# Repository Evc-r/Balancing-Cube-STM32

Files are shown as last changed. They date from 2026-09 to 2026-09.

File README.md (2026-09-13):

# STM32F411/ICM-20948 v2 Self-Balancing Cube

Firmware and integration work for a three-axis reaction-wheel balancing cube based on the open-source [remrc/Self-Balancing-Cube](https://github.com/remrc/Self-Balancing-Cube) project.

This version replaces the original ESP32 and MPU6050 with:

- **STM32F411CEU6** microcontroller
- **ICM-20948 v2 breakout** intelligent IMU
- Three **Nidec 24H** reaction-wheel motors with integrated drivers and quadrature encoders
- **3S LiPo** power system

> [!WARNING]
> This project contains high-speed reaction wheels and a LiPo battery. Incorrect PWM polarity, wiring, firmware, or mechanical assembly can cause an unexpected full-power motor start. Read the safety section and complete every diagnostic stage before enabling closed-loop balancing.

## Project status

**Current phase: transitioning into firmware development and software integration.** CAD and the first custom PCB design are complete; electrical bring-up and balancing validation remain ahead.

| Area | Current progress |
|---|---|
| Mechanical design / CAD | Complete for the current build |
| Mechanical assembly | Frame and reaction-wheel assembly completed; final wiring/integration remains |
| Custom four-layer PCB | First design complete and sent for fabrication; known issues require rework and validation |
| STM32 connection | Header spacing mismatch identified; plan to connect the board through wires |
| IMU connection | J7 connector unavailable; plan to solder the IMU wiring directly |
| Firmware | Next active development phase: STM32 project setup, peripheral bring-up, and integration |
| Closed-loop balancing | Not yet demonstrated or validated |

### Current hardware issues

- **Power protection:** an unintended VBAT connection was identified that may bypass the protection stage. A trace-isolation/bodge-wire repair is planned. The repair and its effectiveness have not yet been verified.
- **STM32 header spacing:** the PCB's two long header rows do not match the STM32 board. A wired connection is planned, with a pin-by-pin wiring map and continuity checks before power-up.
- **IMU J7 connection:** direct-soldered wiring is planned because the connector is unavailable. Pin order, logic compatibility, and strain relief still need verification.

These are open integration tasks, not completed fixes. The first PCB revision should not be treated as a validated design for replication.

### Next milestones

1. Document the as-built wiring and verify the PCB rework, power rails, and pin allocation.
2. Create the STM32CubeIDE project and establish basic diagnostics.
3. Bring up safe motor PWM/brake control and validate the encoders.
4. Integrate and characterize the ICM-20948 v2.
5. Implement attitude estimation, calibration, and fault handling.
6. Perform output-limited control tests, then tune vertex balancing.
7. Add edge balancing and usability features after the initial controller is reliable.

See [JOURNAL.md](JOURNAL.md) for retrospective CAD/PCB notes and future session logs, and [PROJECT_PLAN.md](PROJECT_PLAN.md) for the planned architecture and acceptance criteria.

### Documentation and project files

The repository currently contains project documentation, not a buildable firmware release. CAD, KiCad source files, manufacturing outputs, photos, and firmware still need to be added here. The existing [project media folder](https://drive.google.com/drive/folders/1Wyz73s2HkP9Nr1Q7drfzrUGMNGJb-3j-?usp=drive_link) is linked for reference.

Earlier CAD/PCB work is documented retrospectively without reconstructed work hours. Future sessions should record what changed, evidence, test results, and actual tracked time.

## Why this is a firmware port, not a board substitution

The original Arduino/ESP32 sketch cannot be compiled unchanged for this hardware. Several subsystems are fundamentally different:

| Original design | This design |
|---|---|
| ESP32 Arduino | STM32CubeIDE and STM32 HAL |
| MPU6050 raw accelerometer/gyro | ICM-20948 v2 raw accelerometer/gyro with STM32 attitude estimation |
| Original complementary filter | STM32 complementary/Mahony filter using calibrated ICM-20948 data |
| GPIO encoder interrupts | STM32 hardware timer encoder mode |
| ESP32 LEDC PWM | STM32 timer PWM |
| EEPROM API | Versioned internal Flash record with CRC |
| BluetoothSerial | USB CDC or UART initially |
| 15 ms `millis()` loop | Deterministic 200 Hz hardware-timed loop |

The original three-wheel coordinate transformations and controller concept remain useful, but controller gains, timing, calibration, drivers, and safety behavior must be implemented and tested again.

## Hardware

### Required core components

- STM32F411CEU6 board, typically a Black Pill-style board
- ICM-20948 v2 breakout
- Three Nidec 24H motors with integrated motor electronics and encoder outputs
- 3S LiPo battery and suitable connector
- Regulated logic supply appropriate for the selected STM32 board and peripherals
- Motor brake, direction, PWM, and encoder wiring
- Battery-voltage divider
- Active buzzer or another fault indicator
- USB-to-UART adapter if USB CDC is not used
- Physical power disconnect

### Items that must be verified before connection

ICM-20948 v2 breakout and STM32 breakout boards vary. Confirm from the actual boards and schematics:

- STM32 board HSE frequency; this project currently assumes 25 MHz
- ICM-20948 v2 regulator and permitted supply voltage
- ICM-20948 v2 logic voltage, pull-ups, level shifters, and interface-selection pins
- Motor encoder output voltage and whether it is push-pull or open-collector
- Need for external encoder pull-ups
- Maximum battery-divider voltage at a fully charged 3S pack
- Ground continuity between logic, IMU, motors, and battery measurement

Do not assume that a module accepting 5 V power also has 5 V-safe signal pins.

## Planned firmware architecture

The architecture, interfaces, safety behavior, and timing values below are implementation targets. Firmware bring-up, execution timing, and successful balancing have not been verified.

```text
ICM-20948 v2 interrupt
    -> SPI or I2C transfer
    -> register/FIFO driver and sample validation
    -> calibrated accelerometer and gyro sample
    -> STM32 attitude estimator
    -> latest timestamped quaternion and angular rate

200 Hz control timer
    -> validate IMU freshness
    -> read three encoder counters
    -> calculate quaternion balance error
    -> determine vertex, edge, fallen, or fault state
    -> run state-feedback controller
    -> mix X/Y/Z corrections into three wheel commands
    -> update PWM, direction, and brake

Background processing
    -> command interface and telemetry
    -> calibration workflow
    -> Flash parameter storage
    -> battery monitoring
    -> diagnostics and fault reporting
```

Serial output, Flash writes, and blocking IMU transfers must never run inside the control interrupt.

## Clock and timing

A 25 MHz external crystal is assumed for the selected board and still needs confirmation; it is not the intended CPU speed. The STM32F411 will be configured through its PLL for a target system clock of **100 MHz**.

Initial timing targets:

| Function | Target |
|---|---:|
| ICM-20948 accelerometer and gyro sampling | 500 Hz initially |
| STM32 attitude estimator | 500 Hz initially |
| Balance controller | 200 Hz initially |
| Motor PWM | 20 kHz |
| Maximum accepted IMU age | 15 ms initially |

The final CubeMX clock tree must also produce a valid peripheral clock if USB CDC is enabled.

## ICM-20948 v2 approach

The ICM-20948 is a 9-axis IMU containing a 3-axis gyroscope, 3-axis accelerometer, AK09916 3-axis magnetometer, FIFO, programmable filters, and an embedded DMP. It supports SPI up to 7 MHz or I2C up to 400 kHz. The initial controller will read raw accelerometer and gyroscope data and perform attitude estimation on the STM32.

Initial sensing strategy:

- Gyroscope and accelerometer sampled at 500 Hz
- Configurable digital low-pass filtering
- Startup stationary gyro-bias calibration
- Six-axis complementary or Mahony quaternion estimator on the STM32
- Magnetometer disabled for balancing initially because motor currents can disturb it
- DMP integration deferred until the raw-data controller is validated

SPI is preferred for deterministic high-rate acquisition. I2C is acceptable for initial testing if the breakout exposes it more conveniently. Connect and use the data-ready interrupt. Every accepted sample must be timestamped locally, checked for plausibility, and monitored for staleness.

The exact v2 breakout must be inspected for its regulator, level shifting, pull-ups, address selection, and exposed interrupt/chip-select pins. The bare ICM-20948 has lower VDDIO limits than the STM32's 3.3 V logic, so compatibility depends on the breakout circuitry.

## Coordinate frames

All sensor measurements must be transformed into a documented mechanical cube frame before they reach the controller.

The mapping will be bench-tested so that positive physical rotation around cube X, Y, and Z produces positive cube-frame gyro X, Y, and Z respectively. Axis swaps and sign changes will be centralized in one module rather than distributed through the controller.

The wheel numbering, positive rotation direction, encoder sign, and cube-frame force direction will also be documented before closed-loop testing.

## Calibration

The MPU6050 offset procedure will be replaced with two layers: stationary accelerometer/gyro calibration, followed by quaternion reference calibration for the mechanical vertex and edge poses.

The firmware will store:

- Vertex reference quaternion
- Edge reference quaternion
- Sensor-to-cube mapping
- Controller gains
- Battery calibration
- Version, record length, magic value, and CRC32

At runtime the orientation error is calculated from:

```text
q_error = inverse(q_reference) * q_current
```

Calibration will only be accepted when IMU data is fresh, sensor accuracy is acceptable, gyro magnitude is low, and the pose remains stable for a defined interval.

Planned commands:

```text
cal vertex
cal edge
cal status
save
```

An absent, corrupt, or incompatible calibration record must prevent balancing.

## Controller

The controller will retain the reference project's general state-feedback structure while using explicit units:

```text
wheel command =
      angle gain * angle error
    + gyro gain * angular velocity
    + wheel velocity gain * wheel velocity
    + wheel position gain * accumulated wheel position
```

Yaw damping uses vertical-axis gyro and combined wheel motion.

The reference three-wheel transformation will be ported and verified against the actual wheel layout:

```text
m1 = (0.5*x - 0.866*y) / 1.37 + z
m2 = (0.5*x + 0.866*y) / 1.37 + z
m3 = -x / 1.37 + z
```

Original numeric gains will not be copied blindly. The new firmware uses different units, sample timing, sensor latency, encoder scaling, and motor-command scaling.

## Development environment

Planned tools:

- STM32CubeIDE
- STM32CubeMX configuration integrated with CubeIDE
- ST-LINK programmer/debugger
- Git
- Serial terminal
- Multimeter
- Oscilloscope or logic analyzer strongly recommended

The repository will eventually contain the complete CubeIDE project and generated configuration needed for a clean build.

## Planned source layout

```text
Core/Inc/                Public module headers
Core/Src/                Application and driver implementation
Drivers/                 STM32 HAL and device support
Docs/                    Wiring, coordinate frames, calibration, and tuning
Tests/                   Host-side and hardware test support
JOURNAL.md               Retrospective hardware notes and future session logs
PROJECT_PLAN.md          Detailed engineering plan
README.md                 Project overview and bring-up guide
```

## Bring-up order

Do not skip ahead to balance tuning. Each stage is a gate for the next.

### 1. Power and MCU

- Verify every regulated rail without motor output enabled.
- Confirm the STM32 HSE and generated 100 MHz clock.
- Establish UART or USB diagnostics.
- Report firmware version and reset cause at boot.

### 2. Brake and PWM

- Assert brake before PWM initialization.
- Test one motor at a time at a low command limit.
- Verify direction control.
- Measure the real zero-torque PWM polarity.
- Confirm reset and debugger attachment never start a motor.

The reference Nidec interface uses active-low PWM. Treat that as a hypothesis to verify electrically, not an assumption.

### 3. Encoders

- Configure timer encoder mode where possible.
- Verify both channels of each encoder.
- Test direction, stationary noise, wraparound, and maximum speed.
- Document positive directions and counts per revolution.

### 4. ICM-20948 v2

- Verify WHO_AM_I and configure the register banks, ranges, filters, FIFO, and data-ready interrupt.
- Read calibrated accelerometer and gyro samples continuously.
- Run the STM32 attitude estimator and measure sample interval, age, bias, saturation, and communication errors.
- Verify all cube-frame axes.
- Confirm individual motor operation does not interrupt reports.

### 5. Calibration and storage

- Capture stable vertex and edge references.
- Save a versioned record with CRC.
- Verify save, reboot, load, and corrupt-record behavior.

### 6. Output-limited closed-loop testing

- Use a support or tether.
- Apply a low motor-command limit.
- Verify by hand that every correction opposes the fall.
- Test stale-IMU and excessive-tilt shutdown.

### 7. Vertex tuning

- Tune angle feedback.
- Add gyro damping.
- Add wheel-velocity feedback.
- Add a small wheel-position term to prevent saturation.
- Add yaw damping.

### 8. Edge balancing and refinements

Only after vertex balance is reliable:

- Implement edge state detection and reference
- Tune an independent edge controller
- Add wireless tuning
- Add status LEDs and improved telemetry

## Serial interface

Initial transport will be UART or USB CDC. Planned commands include:

```text
help
status
faults
imu
encoders
battery
motor <1|2|3> <command>
motor stop
brake <on|off>
cal vertex
cal edge
cal status
save
set <parameter> <value>
get <parameter>
telemetry <on|off>
```

Manual motor commands will only work in a diagnostic state with the balance controller disabled.

## Safety behavior

The firmware must disable motor output if any of these conditions occurs:

- Boot or calibration is in progress
- IMU data is missing, invalid, saturated, or stale
- ICM-20948 v2 identity/configuration check fails or a reset is detected
- Tilt exceeds the allowed range
- Battery voltage is below the safe threshold
- Encoder plausibility fails
- Control-loop overrun occurs
- A NaN or infinity reaches the controller
- A stop command is received

Physical precautions:

- Wear eye protection during powered tests.
- Use a tether or fixture for initial control tests.
- Keep hands, hair, tools, and loose wiring away from the wheels.
- Secure the LiPo and all connectors mechanically.
- Keep an accessible power disconnect.
- Do not charge the LiPo inside the cube.
- Use independent undervoltage and charging protection appropriate for the pack.
- Never write Flash while the cube is balancing.

## Testing and telemetry

Host-side tests are planned for:

- Quaternion normalization, inversion, and sign handling
- Reference-orientation error
- Coordinate transformations
- Three-wheel mixing and inverse mixing
- Saturation and accumulated-state limits
- Flash record CRC and version checks
- Fault-state transitions

Runtime telemetry will include:

- Control-loop execution time
- IMU sample age and accuracy
- Quaternion and angle errors
- Gyro values
- Encoder deltas and wheel velocities
- Individual controller terms
- Motor commands before and after saturation
- Battery voltage
- Active state and fault flags

## Definition of the first release

Version `v0.1.0` will require:

- A clean build from documented STM32CubeIDE prerequisites
- Documented pin map and wiring
- Passing motor and encoder diagnostics
- Timestamped and fault-monitored ICM-20948 v2 samples and STM32 attitude estimates
- CRC-protected vertex calibration
- Repeatable vertex balance without wheel-speed saturation
- Reliable stale-IMU, over-tilt, low-battery, and software-fault shutdown
- Documented controller units, gains, calibration, and bring-up procedure

Edge balancing may ship in a later release if it is not reliable enough for `v0.1.0`.

## Contributing and development notes

Until the first hardware bring-up is complete, interface definitions, pin assignments, and controller parameters should be considered provisional.

When making changes:

- Keep hardware access separate from control mathematics.
- State physical units in names or comments.
- Do not mix sensor-frame and cube-frame values.
- Include safe defaults and failure behavior.
- Update documentation whenever pin assignments, coordinate signs, or calibration data change.
- Record test conditions and telemetry when changing controller gains.

## Acknowledgements

This project is derived from and inspired by Remigijus's [Self-Balancing-Cube](https://github.com/remrc/Self-Balancing-Cube). The original repository established the mechanical concept, Nidec motor interface, wheel mixing, balance-control structure, and practical build approach.

This repository is an independent STM32F411/ICM-20948 v2 port and will require new firmware, calibration, validation, and gain tuning.

## License

No license has been selected yet. Until a license file is added, normal copyright restrictions apply to original work in this repository. Any reused or adapted material must continue to comply with its original licensing terms.

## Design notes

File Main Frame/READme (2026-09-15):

Please note that the current CAD files (V1) committed to this Github are NOT FINAL, and have been changed, edited, and finished since publication.

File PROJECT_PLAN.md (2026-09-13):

# STM32F411/ICM-20948 v2 Self-Balancing Cube Project Plan

## Current progress

CAD and mechanical assembly are completed. The first custom four-layer PCB design is completed and was sent for fabrication. The project is moving into firmware development/software integration. PCB rework and electrical validation are still pending; firmware bring-up and successful balancing have not been verified.

The custom PCB is part of the current build. A VBAT connection may bypass the protection circuit; a bodge repair is planned, but its completion and effectiveness are unverified. The STM32 header spacing is incorrect, so a wired STM32 connection is planned. The J7 IMU connector is unavailable, so directly soldering its wiring is planned. These repairs and connections have not been verified.

The architecture, rates, and interfaces below are **implementation targets**, not measured performance or completed firmware. M0 remains an open validation gate; M1–M9 are upcoming milestones. See [README.md](README.md) for the status summary and [JOURNAL.md](JOURNAL.md) for progress notes.

## 1. Goal

Port and improve the control system from [remrc/Self-Balancing-Cube](https://github.com/remrc/Self-Balancing-Cube) for this hardware:

- STM32F411CEU6 microcontroller, with an assumed 25 MHz HSE to confirm and a target 100 MHz system clock
- ICM-20948 v2 breakout IMU
- Three Nidec 24H reaction-wheel motors with direction, active-low PWM, shared brake, and quadrature encoders
- 3S LiPo power system

The first release target is safe, repeatable vertex balancing. Edge balancing and wireless tuning come afterward.

## 2. Scope

### Included

- Integration and validation of the existing custom four-layer PCB
- Native STM32CubeIDE/HAL firmware
- Three 20 kHz motor PWM outputs
- Three direction outputs and one shared brake output
- Three hardware quadrature encoder interfaces where pin mapping permits
- ICM-20948 v2 quaternion and calibrated gyro acquisition
- Sensor-to-cube coordinate transformation
- Quaternion-based vertex and edge calibration
- State-feedback balance controller
- Battery monitoring and fault shutdown
- USB CDC or UART diagnostics
- Flash-backed calibration and parameter storage

### Deferred until balancing works

- Bluetooth/BLE tuning
- WS2812 status LEDs
- Automated gain tuning
- Jump-up maneuver

## 3. Main changes from the reference firmware

| Reference project | This project |
|---|---|
| ESP32 Arduino | STM32CubeIDE with STM32 HAL |
| ESP32 LEDC PWM | STM32 timer PWM |
| GPIO encoder interrupts | Hardware timer encoder mode |
| MPU6050 raw readings | ICM-20948 v2 register/FIFO accelerometer and gyro samples |
| Original complementary filter | STM32 complementary/Mahony quaternion estimator |
| Accelerometer offset calibration | Quaternion reference calibration |
| EEPROM API | Internal Flash record with version and CRC |
| BluetoothSerial | USB CDC or UART first; external wireless later |
| 15 ms millis loop | Deterministic 200 Hz hardware-timed loop |

The original three-wheel mixing and controller structure will be retained only after signs, units, and scaling are verified.

## 4. Architecture

```text
ICM-20948 data-ready INT
    -> SPI/I2C register or FIFO transfer
    -> calibrated accelerometer + gyro sample
    -> STM32 attitude estimator
    -> latest timestamped quaternion + angular rate

200 Hz control timer
    -> copy latest valid IMU sample
    -> read encoder counters
    -> calculate quaternion error from balance reference
    -> run vertex/edge state machine
    -> run state-feedback controller
    -> convert X/Y/Z command to three wheel commands
    -> update PWM, direction, and brake

Background tasks
    -> serial commands and telemetry
    -> calibration workflow
    -> Flash save/load
    -> battery measurement
    -> fault reporting
```

The control interrupt must never print serial data, write Flash, or perform a blocking ICM-20948 v2 transaction.

## 5. Proposed repository structure

```text
Core/Inc/
  app_config.h
  app_types.h
  balance_controller.h
  icm20948_driver.h
  calibration.h
  command_interface.h
  coordinate_transform.h
  encoder.h
  fault_manager.h
  motor_control.h
  parameter_store.h
  telemetry.h
Core/Src/
  balance_controller.c
  icm20948_driver.c
  calibration.c
  command_interface.c
  coordinate_transform.c
  encoder.c
  fault_manager.c
  motor_control.c
  parameter_store.c
  telemetry.c
  main.c
Docs/
Tests/
PROJECT_PLAN.md
README.md
JOURNAL.md
```

Keep hardware access outside the controller mathematics so transforms, mixing, safety logic, and quaternion calculations can be unit tested.

## 6. Units and core data

Use explicit units everywhere:

- Angle: radians
- Angular velocity: radians/second
- Wheel velocity: counts/second initially, later radians/second
- Control period: seconds
- Motor command: normalized -1.0 to +1.0
- Battery voltage: volts

```c
typedef struct { float w, x, y, z; } Quaternion;
typedef struct { float x, y, z; } Vector3f;

typedef struct {
    Quaternion orientation;
    Vector3f accel_m_s2;
    Vector3f gyro_rad_s;
    uint32_t timestamp_us;
    uint8_t validity and saturation status;
    bool valid;
} ImuSample;

typedef struct {
    uint32_t version;
    Quaternion vertex_reference;
    Quaternion edge_reference;
    float sensor_to_cube_rotation[3][3];
    uint32_t crc32;
} CalibrationRecord;
```

## 7. Hardware and CubeMX plan

### Clock

- Confirm the board actually uses a 25 MHz HSE.
- Configure the PLL for a 100 MHz system clock.
- Verify APB timer clocks in CubeMX.
- If USB CDC is used, ensure a valid 48 MHz USB clock.
- Measure a timed GPIO output to confirm the generated clock configuration.

### Timer allocation

Conceptual allocation only; final assignments depend on exposed pins and alternate-function conflicts:

```text
TIM1 CH1-CH3: motor PWM 1-3
TIM2 CH1/CH2: encoder 1
TIM3 CH1/CH2: encoder 2
TIM4 CH1/CH2: encoder 3
TIM5: control scheduler or microsecond time base
```

Complete the CubeMX pin allocation before permanent harness or PCB wiring. If all three encoder timers cannot be mapped, use hardware encoder mode for the fastest wheels and a validated interrupt decoder for the remaining wheel.

### Motor interface

- PWM frequency: 20 kHz.
- Preserve active-low PWM until verified with a meter or oscilloscope.
- Initialize every PWM compare register to zero-torque before releasing brake.
- Keep the shared brake asserted during boot, faults, Flash writes, and debugger halts.
- Test one motor at a time with a low command limit.

### Encoders

- Confirm output voltage and whether outputs are push-pull or open-collector.
- Add external pull-ups if required.
- Do not exceed the selected STM32 pin voltage limits.
- Configure timer input filtering if noise creates false counts.
- Verify the direction sign of every wheel independently.

### ICM-20948 v2

Prefer SPI if the exact ICM-20948 v2 breakout board exposes it correctly. Otherwise use 400 kHz I2C with INT and RESET connected.

Inspect the exact breakout for:

- Regulator configuration
- Logic voltage
- I2C pull-ups
- Level shifters
- Interface-selection pins

Do not assume every board sold as ICM-20948 v2 breakout has the same circuit.

### Battery ADC

- Use a divider safe at maximum charged 3S voltage.
- Ensure the ADC input cannot exceed its limit.
- Add RC filtering near the MCU.
- Calibrate against a multimeter.
- Retain independent LiPo undervoltage protection.

## 8. IMU strategy

The ICM-20948 contains a 3-axis gyroscope, 3-axis accelerometer, AK09916 3-axis magnetometer, FIFO, programmable digital filters, and an embedded DMP. It supports SPI up to 7 MHz or I2C up to 400 kHz.

Initial implementation:

- Read raw accelerometer and gyroscope data through SPI where possible
- Configure suitable full-scale ranges and digital low-pass filters
- Use the data-ready interrupt and optionally the FIFO
- Sample accelerometer and gyro at 500 Hz initially
- Calibrate stationary gyro bias at startup
- Apply stored accelerometer scale/offset correction if characterization shows it is required
- Run a six-axis complementary or Mahony quaternion estimator on the STM32 at 500 Hz
- Run the balance controller at 200 Hz using the freshest complete estimate
- Leave the magnetometer disabled for balancing initially because motor currents can disturb it
- Defer DMP integration until the raw-data controller is validated

SPI is preferred for predictable high-rate acquisition. I2C at 400 kHz is acceptable for early tests. Every sample must be timestamped locally and checked for stale data, clipping, impossible jumps, communication errors, and estimator validity.

The exact v2 breakout must be inspected for regulator, voltage translation, pull-ups, address selection, and exposed INT/CS pins. The bare ICM-20948 has stricter VDDIO limits than 3.3 V, so breakout-level compatibility must be verified rather than assumed.

Initial timing targets:

```text
Accelerometer/gyro sampling: 2 ms (500 Hz)
STM32 attitude estimation:   2 ms (500 Hz)
Control-loop interval:       5 ms (200 Hz)
Maximum accepted sample age: 15 ms initially
```

The controller must enter a safe fault state if samples stop, WHO_AM_I/configuration checks fail, the sensor resets, readings saturate unexpectedly, or the attitude estimator becomes invalid.

## 9. Coordinate frames and calibration

### Sensor-to-cube transform

Implement one central sensor-to-cube transformation. Do not scatter sign swaps through controller code.

Verify on the bench:

- Positive cube rotation around X produces positive cube-frame gyro X.
- Positive cube rotation around Y produces positive cube-frame gyro Y.
- Positive cube rotation around Z produces positive cube-frame gyro Z.

Document the mapping in a future `Docs/COORDINATE_FRAMES.md`.

### Quaternion references

Store separate vertex and edge reference quaternions. At runtime:

```text
q_error = inverse(q_reference) * q_current
```

For small errors:

```text
angle_x ~= 2 * q_error.x
angle_y ~= 2 * q_error.y
angle_z ~= 2 * q_error.z
```

Normalize quaternions and enforce a consistent quaternion hemisphere so equivalent q and -q representations do not cause discontinuities.

Calibration commands:

```text
cal vertex
cal edge
cal status
save
```

Calibration capture requires fresh data, acceptable sensor accuracy, low gyro magnitude, and a stable orientation for a defined duration.

## 10. Controller plan

### Vertex controller

```text
u_x = K_angle_x * angle_error_x
    + K_gyro_x * gyro_x
    + K_wheel_v_x * wheel_velocity_x
    + K_wheel_p_x * wheel_position_x

u_y = K_angle_y * angle_error_y
    + K_gyro_y * gyro_y
    + K_wheel_v_y * wheel_velocity_y
    + K_wheel_p_y * wheel_position_y

u_z = K_yaw_rate * gyro_z
    + K_yaw_wheel * wheel_velocity_z
```

Use saturation and limit accumulated wheel-position terms.

### Three-wheel mixing

Port and verify the reference equations:

```text
m1 = (0.5*x - 0.866*y) / 1.37 + z
m2 = (0.5*x + 0.866*y) / 1.37 + z
m3 = -x / 1.37 + z
```

Verify the inverse transformation against actual wheel locations and encoder signs.

### Tuning order

1. Verify signs through hand-held, output-limited tests.
2. Add low-gain angle feedback.
3. Add gyro damping.
4. Tune angle and gyro terms for bounded behavior.
5. Add wheel-velocity feedback.
6. Add a small wheel-position term to prevent saturation.
7. Add yaw damping.
8. Implement and tune edge balancing separately.

Do not copy the original numeric gains: the units, loop period, IMU latency, encoder scaling, and motor-command scaling have changed.

## 11. Safety requirements

Disable motor output when:

- Firmware is booting or calibrating.
- IMU data is missing, stale, or invalid.
- A ICM-20948 v2 reset is detected.
- Tilt exceeds the configured fall threshold.
- Battery voltage is below the safe threshold.
- Encoder plausibility fails.
- The control loop overruns.
- A NaN or infinity enters the controller.
- An explicit stop command is received.

Additional requirements:

- Begin with a low motor-command limit.
- Use a physical support, tether, eye protection, and an accessible power disconnect.
- Secure the battery and wiring.
- Never write Flash while balancing.
- Ensure debugger halt cannot leave motor PWM active.
- Use independent 3S LiPo protection.

## 12. Serial interface

Initial transport: UART or USB CDC.

Planned commands:

```text
help
status
faults
imu
encoders
battery
motor <1|2|3> <command>
motor stop
brake <on|off>
cal vertex
cal edge
cal status
save
set <parameter> <value>
get <parameter>
telemetry <on|off>
```

Manual motor commands are allowed only in a diagnostic state with the balance controller disabled.

## 13. Flash storage

Store a versioned record containing:

- Magic value
- Structure version and length
- Vertex and edge reference quaternions
- Axis mapping
- Controller gains
- Battery calibration
- CRC32

Invalid magic, version, length, or CRC must load safe defaults and require calibration. Save only with motor output disabled and brake asserted.

## 14. Milestones

### M0 - Hardware confirmation

- Document and verify the planned VBAT/protection repair before powering the integrated system; confirm the intended power path and protection behavior.
- Map and continuity-check the planned wired STM32 connection and direct-soldered IMU connection.
- Record exact STM32 board and ICM-20948 v2 breakout module.
- Confirm motor connector, encoder type, and logic voltage.
- Confirm battery, regulator, divider, and brake wiring.
- Complete a conflict-free CubeMX draft pin map.

Exit: planned repairs and connections are completed and verified, the intended power path and protection behavior are confirmed, and no voltage-level or pin-allocation questions remain.

### M1 - STM32 bring-up

- Generate CubeMX project.
- Verify intended system clock.
- Enable UART or USB logging.
- Add microsecond timing and fault indication.

Exit: measured clock and stable diagnostics.

### M2 - Motor and brake diagnostics

- Configure PWM, direction, and shared brake.
- Reproduce the reference motor test at low command.
- Confirm true zero-torque PWM polarity.

Exit: each motor runs independently in both directions, and resets never cause motion.

### M3 - Encoder bring-up

- Configure three encoder interfaces.
- Measure signed deltas at a fixed interval.
- Test direction, stationary noise, wraparound, and maximum speed.

Exit: all encoders count reliably with documented signs.

### M4 - ICM-20948 v2 bring-up

Tasks:

- Verify WHO_AM_I and banked-register access.
- Configure accelerometer and gyro ranges, sample rates, filters, interrupt, and FIFO if used.
- Calibrate stationary gyro bias.
- Timestamp samples and monitor data age, saturation, and communication faults.
- Implement sensor-to-cube mapping.
- Implement and validate the STM32 attitude estimator.

Exit criteria:

- Raw accelerometer and gyro samples remain continuous while motors run individually.
- Sample interval, bias, clipping, and estimator health are monitored.
- All three cube-frame gyro signs are verified.
- Static orientation estimates are stable and return correctly after slow tilts.
- A disconnected, reset, or misconfigured IMU generates a safe fault.

### M5 - Calibration and persistence

- Capture stable vertex and edge references.
- Implement quaternion error.
- Add versioned Flash storage with CRC.

Exit: calibration survives reboot; absent or corrupt calibration cannot enable balancing.

### M6 - Low-power closed-loop tests

- Port wheel mixing.
- Add output-limited angle and gyro control.
- Verify every correction sign while holding the cube.
- Add stale-data and over-angle shutdown.

Exit: corrections oppose disturbances on both axes, with reliable fault shutdown.

### M7 - Vertex balancing

- Tune angle and gyro terms.
- Add wheel-velocity and wheel-position feedback.
- Add yaw damping and telemetry.

Exit: repeatable balance without wheel saturation and with predictable fall shutdown.

### M8 - Edge balancing

- Determine correct edge axis and wheel combination.
- Implement edge detection and independent gains.

Exit: repeatable edge balance without degrading vertex behavior.

### M9 - Release preparation

- Add optional wireless tuning and status indicators.
- Complete build, wiring, calibration, and tuning documentation.
- Tag the first stable release.

Exit: another person can build, flash, calibrate, and test the cube from the repository instructions.

## 15. Testing and telemetry

Host-side tests should cover:

- Quaternion normalization, inverse, and hemisphere handling
- Reference error calculation
- Coordinate transforms
- Wheel mixing and inverse mixing
- Saturation and accumulated-state limiting
- Flash CRC and version validation
- Fault-state transitions

Telemetry should include:

- Timestamp and loop execution time
- IMU age and accuracy
- Quaternion and angle errors
- Gyro X/Y/Z
- Encoder deltas and wheel velocities
- Individual controller terms
- Saturated and unsaturated motor commands
- Battery voltage
- Active state and fault flags

## 16. Principal risks

| Risk | Mitigation |
|---|---|
| CEU6 timer pin conflicts | Finish CubeMX allocation before wiring |
| Active-low PWM causes startup torque | Measure idle polarity and initialize PWM before brake release |
| Encoder voltage exceeds GPIO limit | Verify electrically and level-shift if required |
| ICM-20948 v2 breakout variants differ | Inspect and document the exact module |
| Fusion latency destabilizes control | Timestamp samples and tune controlled bandwidth |
| Motor magnetic interference | Keep the magnetometer out of the initial balance estimator |
| Quaternion sign discontinuity | Enforce a consistent hemisphere |
| Coordinate signs are incorrect | Centralize and bench-verify transforms |
| Original gains have incompatible units | Retune from low output limits using explicit units |
| Flash stalls execution | Save only while motors are disabled |
| LiPo over-discharge | Conservative thresholds plus independent protection |
| Debug halt leaves motors active | Safe debug configuration and physical disconnect |

## 17. Definition of v0.1.0

The first successful release requires:

- Clean STM32CubeIDE build from documented prerequisites
- Documented wiring and pin map
- Passing motor and encoder diagnostics
- Timestamped and fault-monitored ICM-20948 v2 reports
- CRC-protected vertex calibration
- Repeatable vertex balance without wheel saturation
- Reliable stale-IMU, over-tilt, low-battery, and software-fault shutdown
- Documented controller units and gains
- Complete bring-up and calibration instructions

Edge balancing may be released later if it is not reliable enough for v0.1.0.

## 18. Immediate next actions

Before powered bring-up: document the PCB rework, verify the intended power path and protection behavior after the planned repair, and check the STM32/IMU wiring against the schematic. Add CAD, KiCad sources, and photos to the repository as they become available. Start session-based journaling and time tracking with firmware work.

1. Document both sides and pin labels of the exact STM32F411 and ICM-20948 v2 breakout boards.
2. Confirm the 25 MHz HSE and decide whether USB CDC is required.
3. Build the complete pin inventory and CubeMX timer allocation.
4. Measure motor encoder logic voltage and determine pull-up requirements.
5. Create the STM32CubeIDE project and UART diagnostics.
6. Implement brake-safe boot behavior before applying motor power.
7. Bring up one PWM channel and motor at low command.
8. Bring up its encoder in timer encoder mode.
9. Repeat for all motors and encoders.
10. Implement ICM-20948 v2 communication and log quaternion, gyro, interval, age, and accuracy before writing balance-control code.

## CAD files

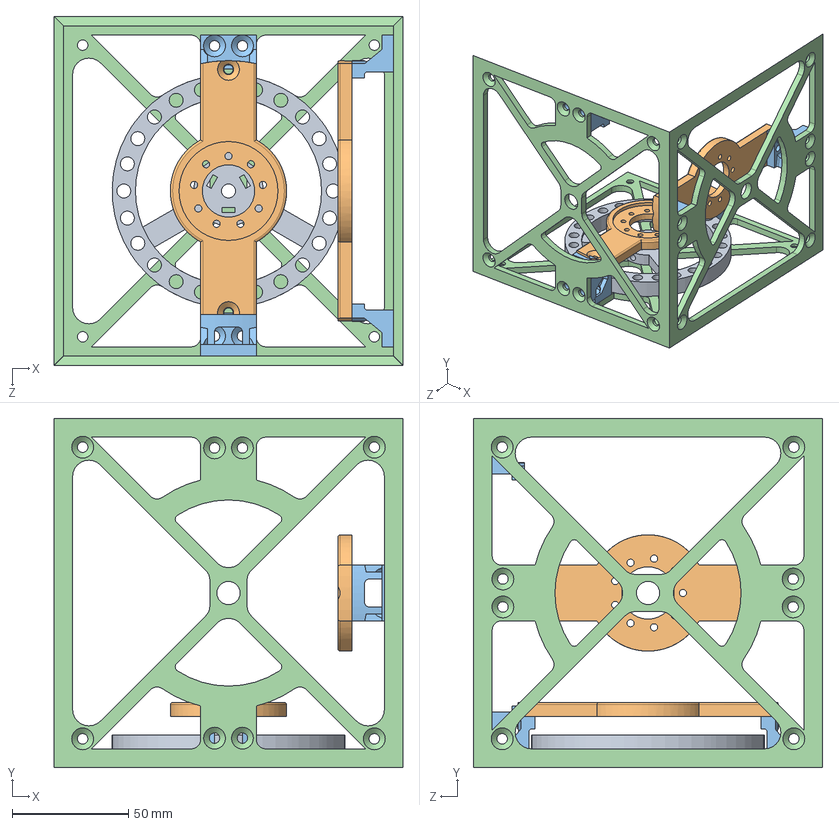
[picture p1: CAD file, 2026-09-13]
Main Frame/Assem1.SLDASM
150.0 x 150.0 x 150.0 mm
rwframev2.2 x 3
motorholderconnectorv0.1 x 3
motorholderv0.1 x 2
reactionwheelv0.1

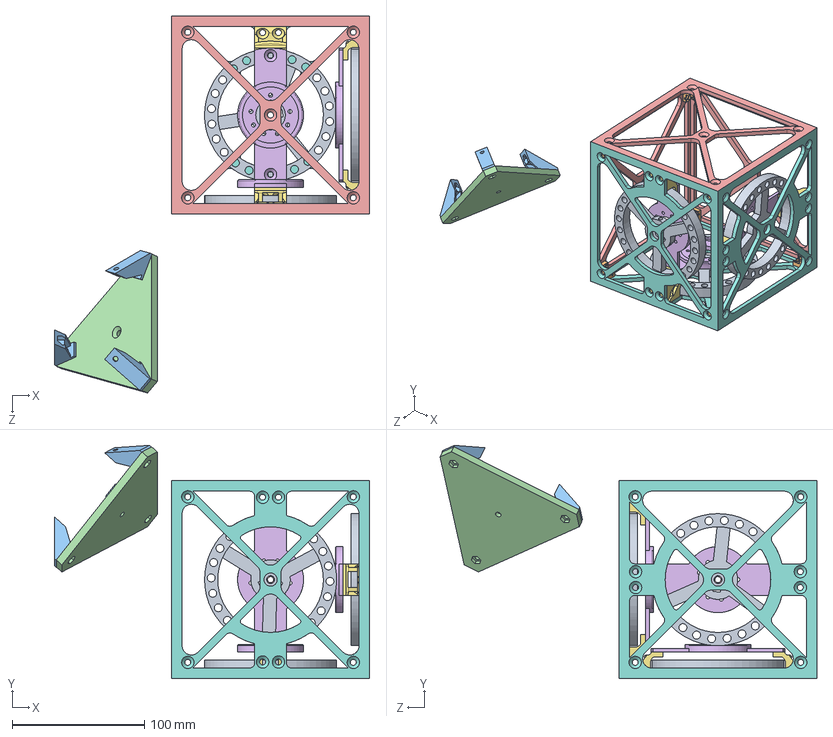
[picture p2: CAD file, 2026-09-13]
Main Frame/Assem2.SLDASM
238.7 x 176.7 x 285.5 mm
rwframev2.2 x 3
motorholderconnectorv0.2 x 3
motorholderv0.2 x 3
nframev0.1 x 3
elecframev0.1
elecframeconnectorv0.1 x 3
cornerconnectorv0.1 x 8
reactionwheelv0.1 x 3

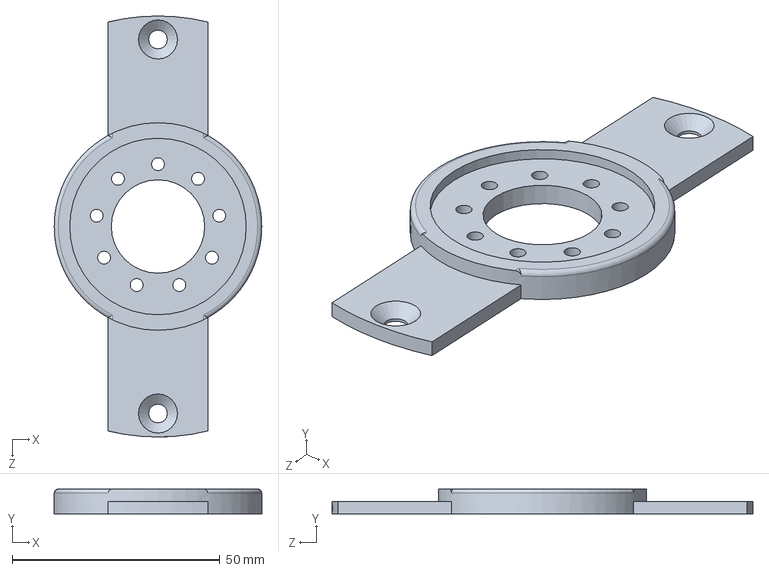
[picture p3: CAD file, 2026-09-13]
Main Frame/motorholderv0.2.SLDPRT
50.0 x 6.00 x 101.4 mm

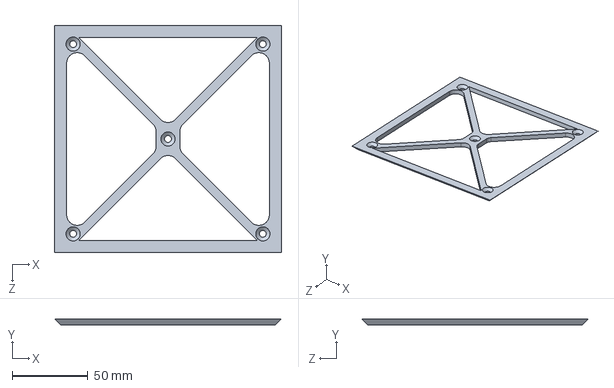
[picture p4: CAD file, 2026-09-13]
Main Frame/nframev0.1.SLDPRT
150.0 x 4.00 x 150.0 mm

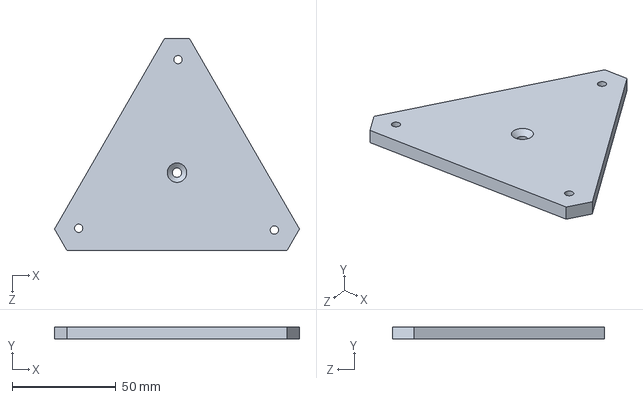
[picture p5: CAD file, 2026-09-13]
Main Frame/elecframev0.1.SLDPRT
118.0 x 6.00 x 102.2 mm

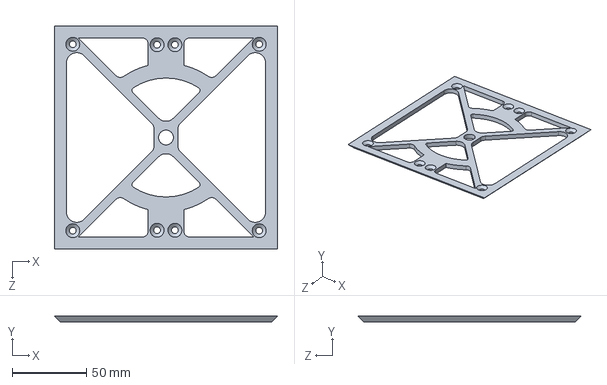
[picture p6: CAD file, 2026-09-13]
Main Frame/rwframev2.2.SLDPRT
150.0 x 4.00 x 150.0 mm

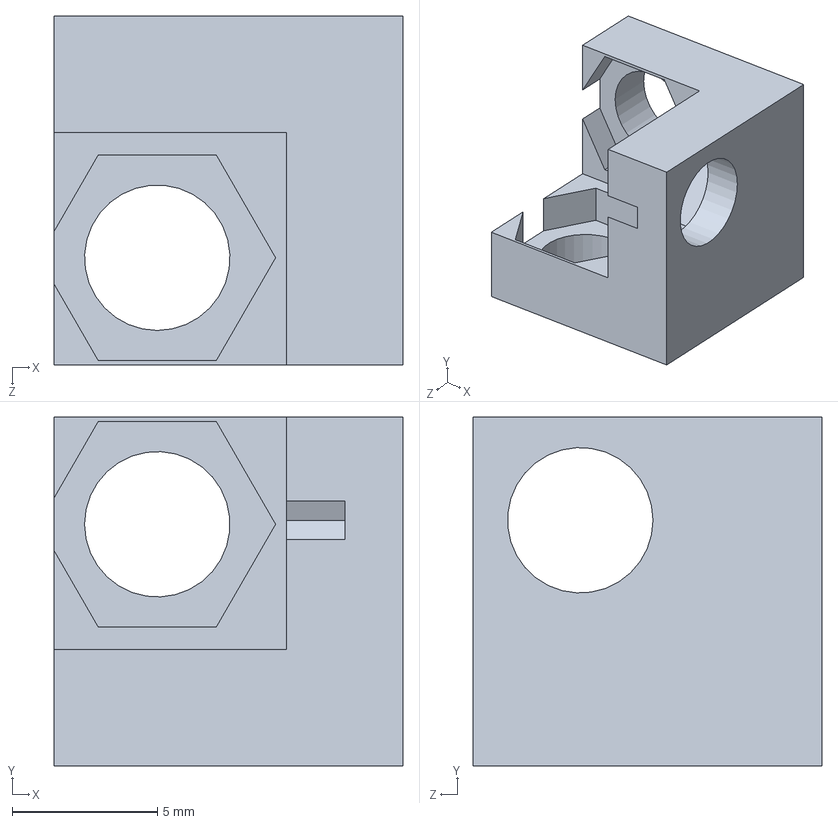
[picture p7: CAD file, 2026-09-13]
Main Frame/cornerconnectorv0.1.SLDPRT
12.0 x 12.0 x 12.0 mm

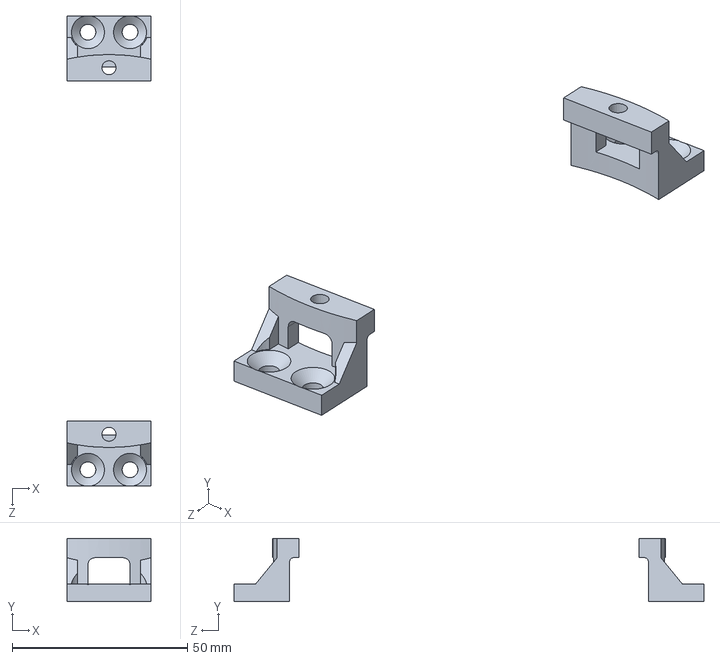
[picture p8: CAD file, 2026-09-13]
Main Frame/motorholderconnectorv0.1.SLDPRT
24.0 x 18.0 x 134.0 mm

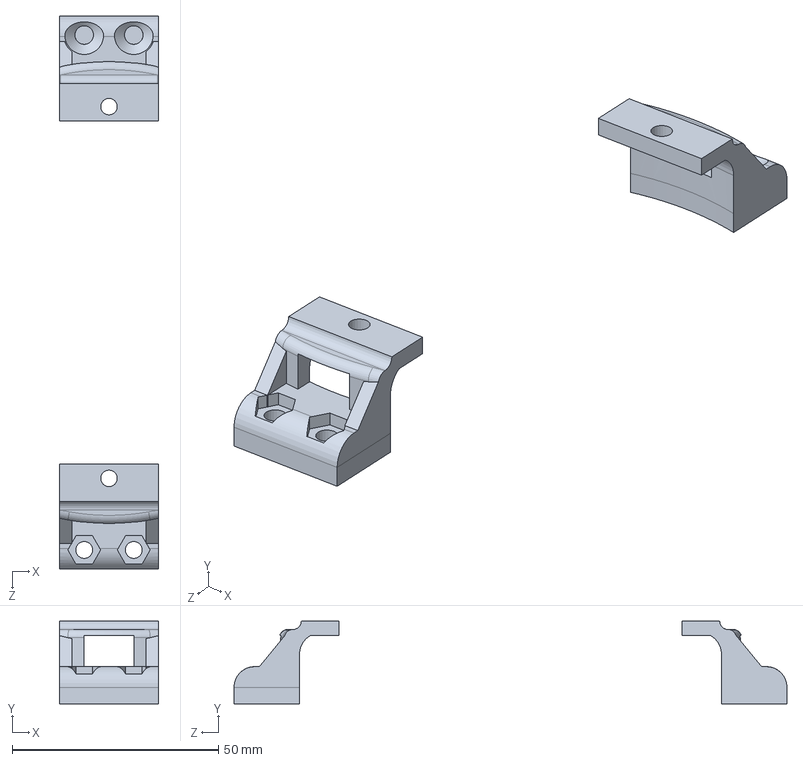
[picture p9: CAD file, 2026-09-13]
Main Frame/motorholderconnectorv0.3.SLDPRT
24.0 x 20.0 x 134.0 mm

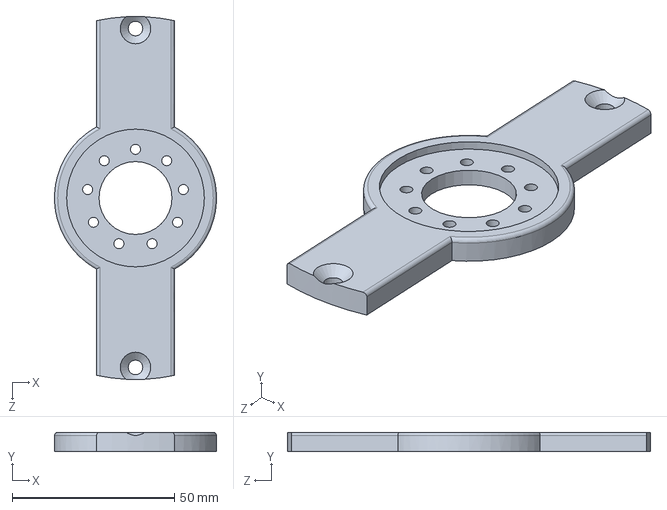
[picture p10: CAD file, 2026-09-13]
Main Frame/motorholderv0.1.SLDPRT
50.0 x 6.00 x 112.0 mm

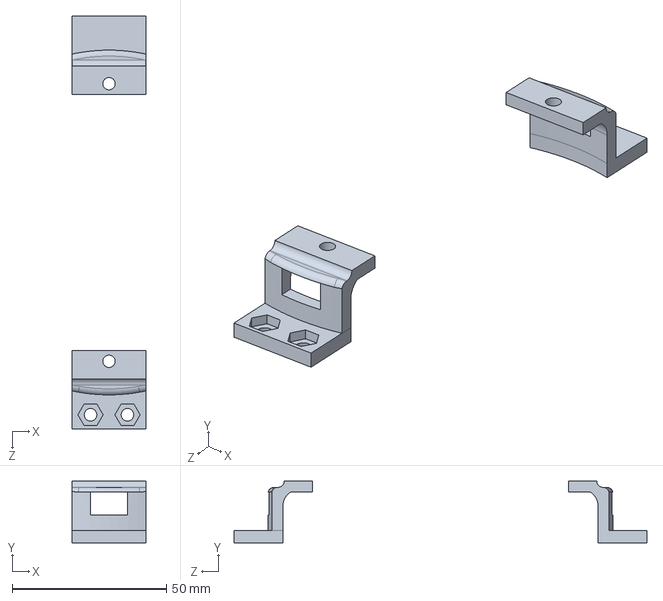
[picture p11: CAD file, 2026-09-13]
Main Frame/motorholderconnectorv0.4 (2).SLDPRT
24.0 x 20.0 x 134.0 mm

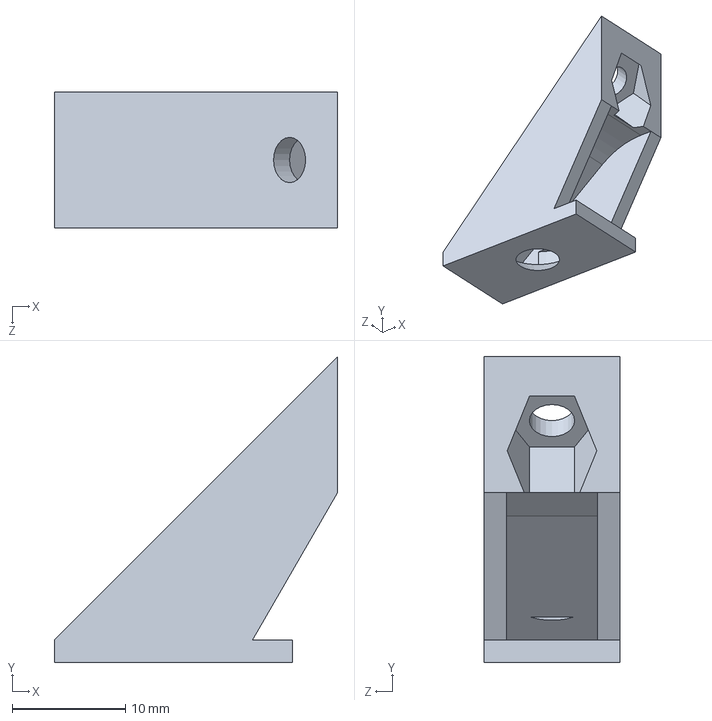
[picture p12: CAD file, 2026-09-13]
Main Frame/elecframeconnectorv0.1.SLDPRT
25.0 x 27.0 x 12.0 mm

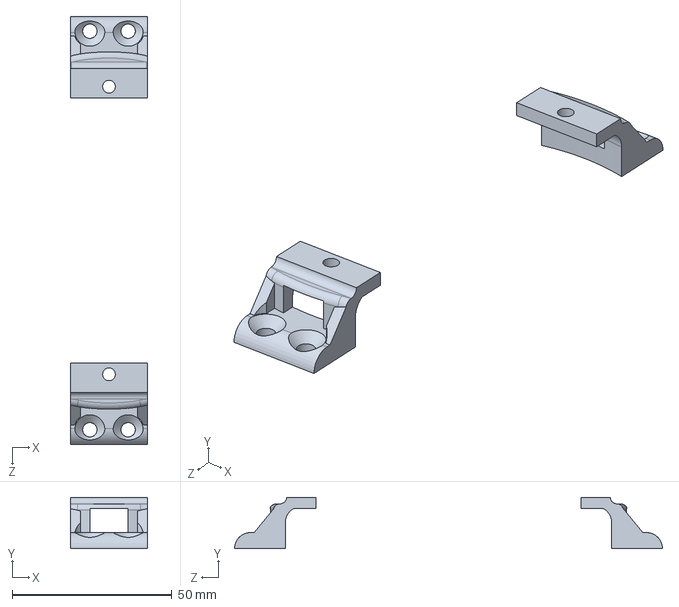
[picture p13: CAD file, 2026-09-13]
Main Frame/motorholderconnectorv0.2.SLDPRT
24.0 x 16.0 x 134.0 mm

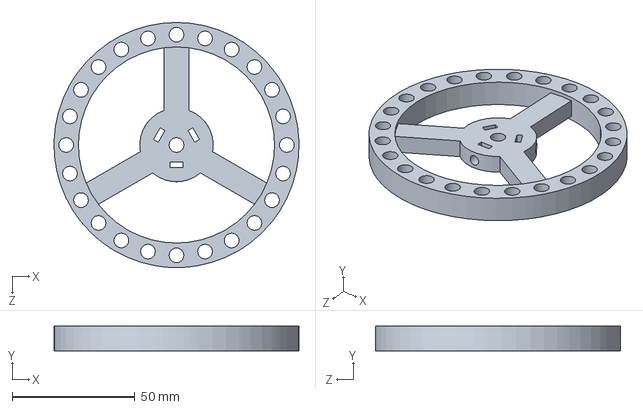
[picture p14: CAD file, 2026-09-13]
Main Frame/reactionwheelv0.1.SLDPRT
100.0 x 10.0 x 100.0 mm

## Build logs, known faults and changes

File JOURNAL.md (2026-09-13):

# Build journal

This journal separates retrospective hardware documentation from firmware sessions recorded as the work happens.

**Status at the start of this journal:** CAD and the first PCB design are complete; the mechanical assembly is completed; firmware development/software integration is the next phase. PCB rework, electrical validation, and balancing tests remain open.

The entries below summarize earlier work. Original session dates and tracked durations were not recorded here, so no hours are claimed. These notes do not establish verified time or funding eligibility.

## Retrospective — Mechanical design and assembly

### Work completed

- Completed the CAD for the current reaction-wheel cube.
- Built the 3D-printed frame and assembled the mechanical system.
- The design uses three Nidec 24H reaction-wheel motors.

### Current outcome

The mechanical build is ready to move into electrical integration and firmware development. Final wire routing, strain relief, and powered validation remain part of integration.

### Evidence to add

- CAD source and STEP/STL exports.
- Assembly and motor-mount screenshots.
- Photos of the printed parts and assembled cube.

These files are not yet included in this repository. The existing [project media folder](https://drive.google.com/drive/folders/1Wyz73s2HkP9Nr1Q7drfzrUGMNGJb-3j-?usp=drive_link) is retained as a reference.

**Time:** not recorded; retrospective entry.

## Retrospective — Custom PCB design and integration issues

### Work completed

- Completed the first custom four-layer PCB design and sent it for fabrication.
- Identified issues that need to be addressed during hardware integration.

### Issues and planned actions

| Issue | Planned action | Verification still needed |
|---|---|---|
| An unintended VBAT connection may bypass the protection stage | Isolate the unintended connection and add a bodge wire as required by the actual board connectivity | Confirm isolation, intended power path, and protection behavior |
| STM32 header-row spacing does not match the board | Use wires between the STM32 and PCB | Document the pin mapping; verify continuity, shorts, and mechanical security |
| J7 IMU connector is unavailable | Solder the IMU wiring directly | Verify pin order, voltage compatibility, continuity, and strain relief |

The repairs are planned, not recorded as completed or tested. This journal is not a board-specific cutting or soldering procedure.

### Evidence to add

- KiCad schematic and PCB source files.
- PCB layout and 3D renders.
- Annotated images showing each issue.
- Before/after repair photos and measured verification results.

### Next step

Resolve and verify the hardware integration issues, then proceed through STM32, sensor, and motor bring-up before closed-loop control.

**Time:** not recorded; retrospective entry.

## Upcoming work — Firmware and bring-up

No successful firmware or balancing test is claimed by this entry.

- [ ] Verify PCB rework, power rails, and the as-built pin map.
- [ ] Create and upload the STM32CubeIDE project.
- [ ] Flash the STM32 and establish basic diagnostics.
- [ ] Implement and test motor-safe boot behavior.
- [ ] Bring up motor control and encoders.
- [ ] Read and calibrate the ICM-20948 v2 specified in the project plan.
- [ ] Implement and validate attitude estimation.
- [ ] Add calibration storage and fault handling.
- [ ] Test limited-output feedback with mechanical support.
- [ ] Tune and record the first repeatable balance.

## Template for future sessions

Copy the template below for each real session. Use the actual date and tracked duration; if time was not tracked, say so. Include failures and measurements as well as successful results. Record screen-based work and physical-work evidence as appropriate.

```markdown
## YYYY-MM-DD — Session title

**Time:** actual tracked duration, or "not tracked"
**Evidence:** recording, screenshots, photos, logs, or commit link

### Goal
What I intended to accomplish.

### Work and observations
What I changed, what happened, and what I measured.

### Problems and decisions
What failed, what I investigated, and why I chose the next approach.

### Result
What is now working, with evidence; what is still unverified.

### Next step
The next concrete task.
```

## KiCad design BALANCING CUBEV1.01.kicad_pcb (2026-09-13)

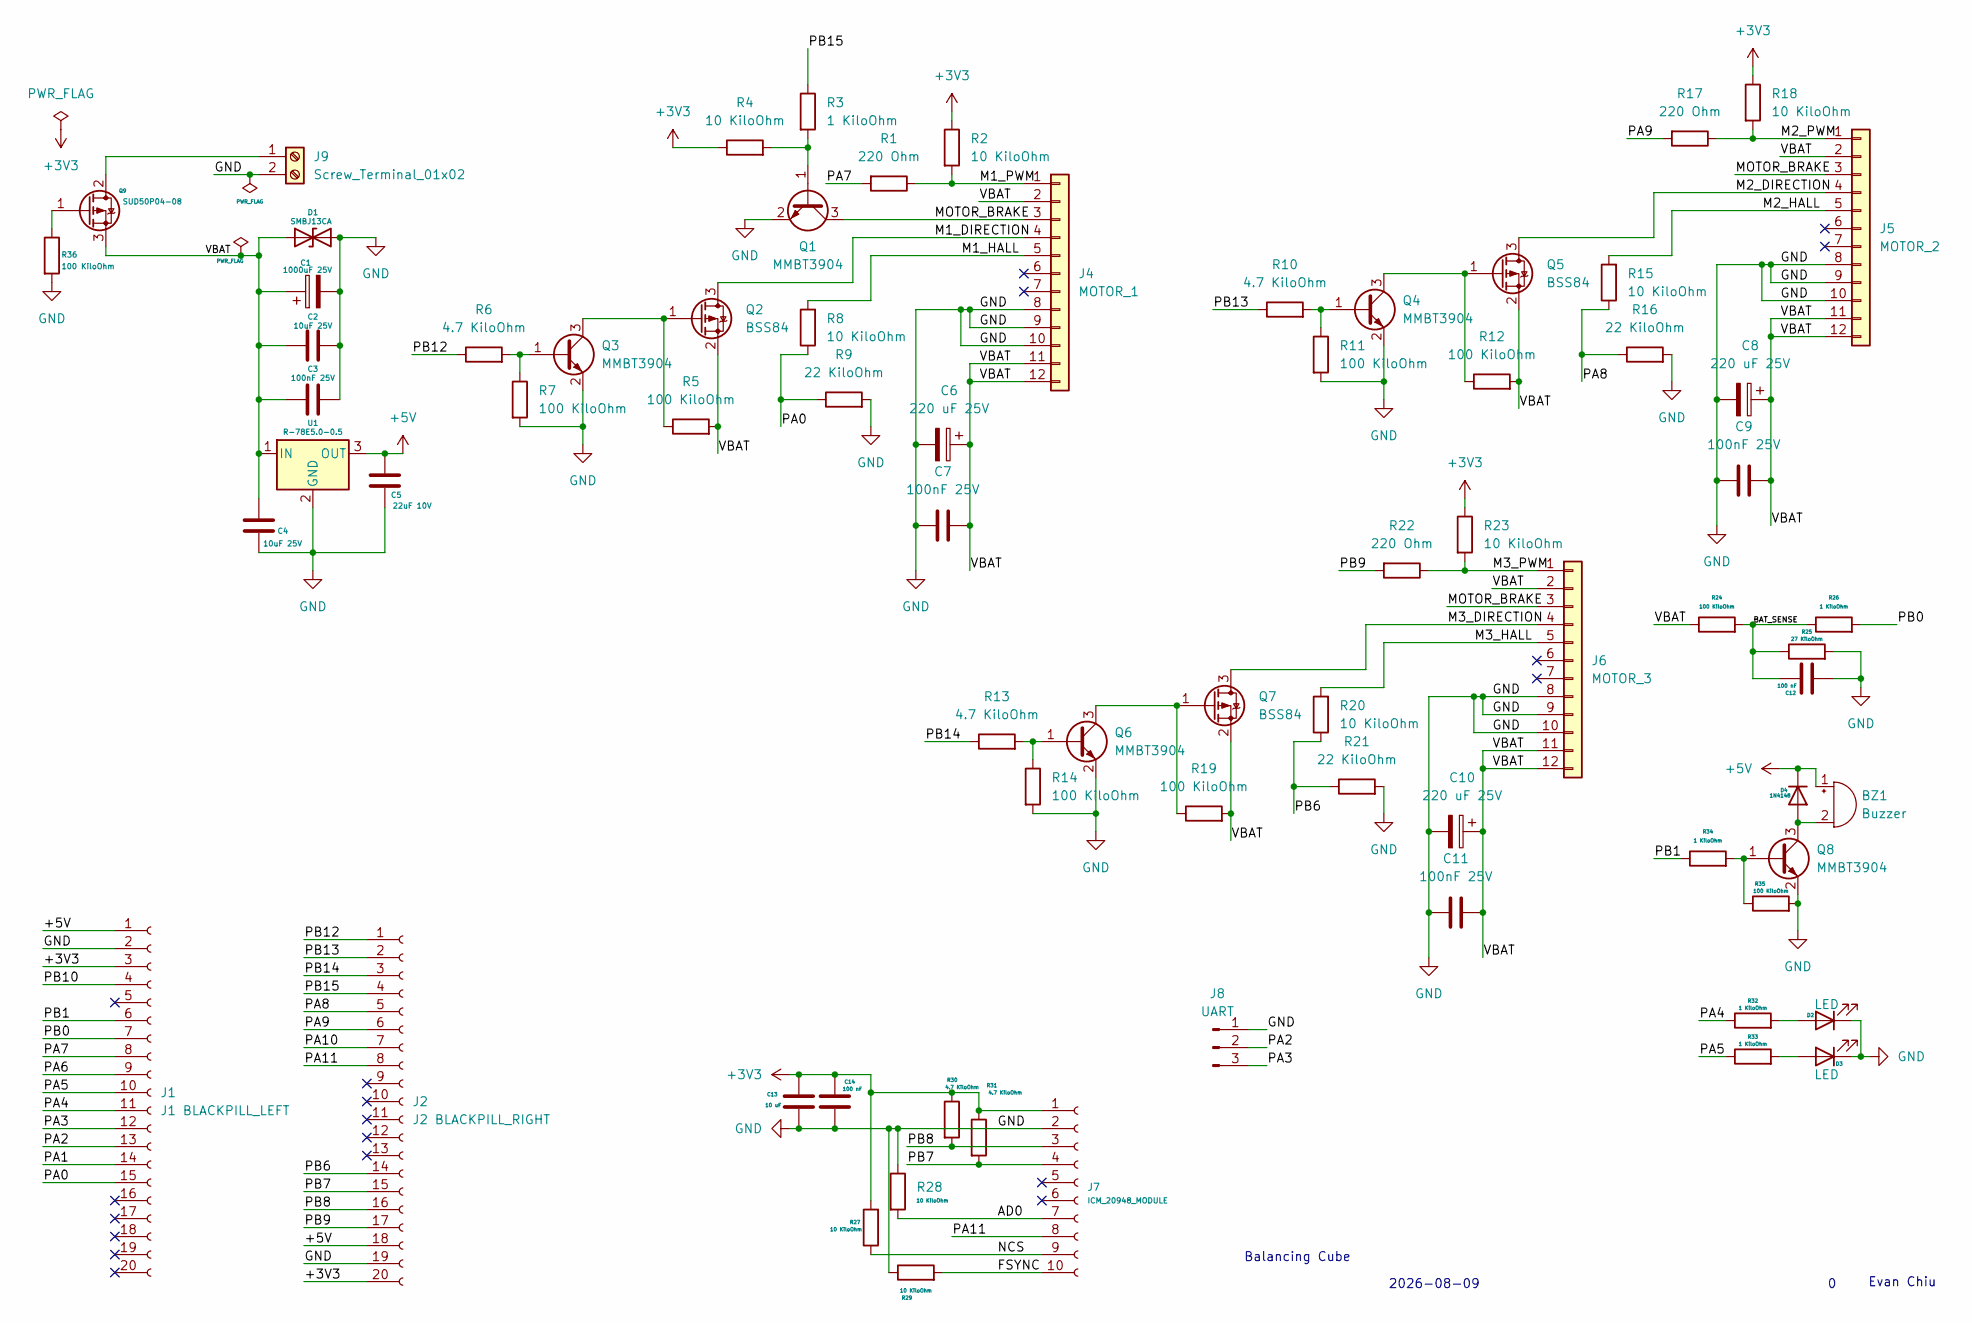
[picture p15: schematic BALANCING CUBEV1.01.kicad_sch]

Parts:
BZ1: Buzzer; Buzzer_12x9.5RM7.6
C1: 1000uF 25V; CP_Radial_D12.5mm_P5.00mm
C2, C4: 10uF 25V; C_1210_3225Metric_Pad1.33x2.70mm_HandSolder
C3, C7, C9, C11: 100nF 25V; C_0805_2012Metric_Pad1.18x1.45mm_HandSolder
C5: 22uF 10V; C_1210_3225Metric_Pad1.33x2.70mm_HandSolder
C6, C8, C10: 220 uF 25V; CP_Radial_D8.0mm_P3.50mm
C12, C14: 100 nF; C_0805_2012Metric_Pad1.18x1.45mm_HandSolder
C13: 10 uF; C_1210_3225Metric_Pad1.33x2.70mm_HandSolder
D1: SMBJ13CA; D_SMB
D2, D3: LED; LED_D3.0mm
D4: 1N4148; D_SOD-123
J1: J1 BLACKPILL_LEFT; PinSocket_1x20_P2.54mm_Vertical
J2: J2 BLACKPILL_RIGHT; PinSocket_1x20_P2.54mm_Vertical
J4: MOTOR_1; JST_ZH_B12B-ZR_1x12_P1.50mm_Vertical
J5: MOTOR_2; JST_ZH_B12B-ZR_1x12_P1.50mm_Vertical
J6: MOTOR_3; JST_ZH_B12B-ZR_1x12_P1.50mm_Vertical
J7: ICM_20948_MODULE; PinSocket_1x10_P2.54mm_Horizontal
J8: UART; PinHeader_1x03_P2.54mm_Vertical
J9: Screw_Terminal_01x02; TerminalBlock_Phoenix_MKDS-3-2-5.08_1x02_P5.08mm_Horizontal
Q1, Q3, Q4, Q6, Q8: MMBT3904; SOT-23
Q2, Q5, Q7: BSS84; SOT-23
Q9: SUD50P04-08; TO-252-2
R1, R17, R22: 220 Ohm; R_0805_2012Metric_Pad1.20x1.40mm_HandSolder
R2, R4, R8, R15, R18, R20, R23, R27, R28, R29: 10 KiloOhm; R_0805_2012Metric_Pad1.20x1.40mm_HandSolder
R3, R26, R32, R33, R34: 1 KiloOhm; R_0805_2012Metric_Pad1.20x1.40mm_HandSolder
R5, R7, R11, R12, R14, R19, R24, R35, R36: 100 KiloOhm; R_0805_2012Metric_Pad1.20x1.40mm_HandSolder
R6, R10, R13, R30, R31: 4.7 KiloOhm; R_0805_2012Metric_Pad1.20x1.40mm_HandSolder
R9, R16, R21: 22 KiloOhm; R_0805_2012Metric_Pad1.20x1.40mm_HandSolder
R25: 27 KiloOhm; R_0805_2012Metric_Pad1.20x1.40mm_HandSolder
U1: R-78E5.0-0.5; Converter_DCDC_RECOM_R-78E-0.5_THT

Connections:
+3V3: C13.1, C14.1, J1.3, J2.20, J7.1, R2.1, R4.1, R18.1, R23.1, R27.2, R30.1, R31.1
+5V: BZ1.1 (+), C5.1, D4.1 (K), J1.1, J2.18, U1.3 (OUT)
/AD0: J7.7, R28.2
/BAT_SENSE: C12.1, R24.2, R25.1, R26.1
/FSYNC: J7.10, R29.2
/M1_DIRECTION: J4.4, Q2.3 (D)
/M1_HALL: J4.5, R8.2
/M1_PWM: J4.1, R1.1, R2.2
/M2_DIRECTION: J5.4, Q5.3 (D)
/M2_HALL: J5.5, R15.2
/M2_PWM: J5.1, R17.1, R18.2
/M3_DIRECTION: J6.4, Q7.3 (D)
/M3_HALL: J6.5, R20.2
/M3_PWM: J6.1, R22.1, R23.2
/MOTOR_BRAKE: J4.3, J5.3, J6.3, Q1.3 (C)
/NCS: J7.9, R27.1
/PA0: J1.15, R8.1, R9.1
/PA1: J1.14
/PA2: J1.13, J8.2
/PA3: J1.12, J8.3
/PA4: J1.11, R32.1
/PA5: J1.10, R33.1
/PA6: J1.9
/PA7: J1.8, R1.2
/PA8: J2.5, R15.1, R16.1
/PA9: J2.6, R17.2
/PA10: J2.7
/PA11: J2.8, J7.8
/PB0: J1.7, R26.2
/PB1: J1.6, R34.1
/PB6: J2.14, R20.1, R21.1
/PB7: J2.15, J7.4, R31.2
/PB8: J2.16, J7.3, R30.2
/PB9: J2.17, R22.2
/PB10: J1.4
/PB12: J2.1, R6.1
/PB13: J2.2, R10.1
/PB14: J2.3, R13.1
/PB15: J2.4, R3.1
/VBAT: C1.1, C2.1, C3.1, C4.1, C6.1, C7.2, C8.1, C9.2, C10.1, C11.2, D1.1 (A1), J4.2, J4.11, J4.12, J5.2, J5.11, J5.12, J6.2, J6.11, J6.12, Q2.2 (S), Q5.2 (S), Q7.2 (S), Q9.3 (S), R5.2, R12.2, R19.2, R24.1, U1.1 (IN)
GND: C1.2, C2.2, C3.2, C4.2, C5.2, C6.2, C7.1, C8.2, C9.1, C10.2, C11.1, C12.2, C13.2, C14.2, D1.2 (A2), D2.1 (K), D3.1 (K), J1.2, J2.19, J4.8, J4.9, J4.10, J5.8, J5.9, J5.10, J6.8, J6.9, J6.10, J7.2, J8.1, J9.2, Q1.2 (E), Q3.2 (E), Q4.2 (E), Q6.2 (E), Q8.2 (E), R7.2, R9.2, R11.2, R14.2, R16.2, R21.2, R25.2, R28.1, R29.1, R35.2, R36.2, U1.2 (GND)
unnamed: BZ1.2 (-), D4.2 (A), Q8.3 (C)
unnamed: D2.2 (A), R32.2
unnamed: D3.2 (A), R33.2
unnamed: J9.1, Q9.2 (D)
unnamed: Q1.1 (B), R3.2, R4.2
unnamed: Q2.1 (G), Q3.3 (C), R5.1
unnamed: Q3.1 (B), R6.2, R7.1
unnamed: Q4.1 (B), R10.2, R11.1
unnamed: Q4.3 (C), Q5.1 (G), R12.1
unnamed: Q6.1 (B), R13.2, R14.1
unnamed: Q6.3 (C), Q7.1 (G), R19.1
unnamed: Q8.1 (B), R34.2, R35.1
unnamed: Q9.1 (G), R36.1

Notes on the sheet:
Evan Chiu
2026-08-09
Balancing Cube

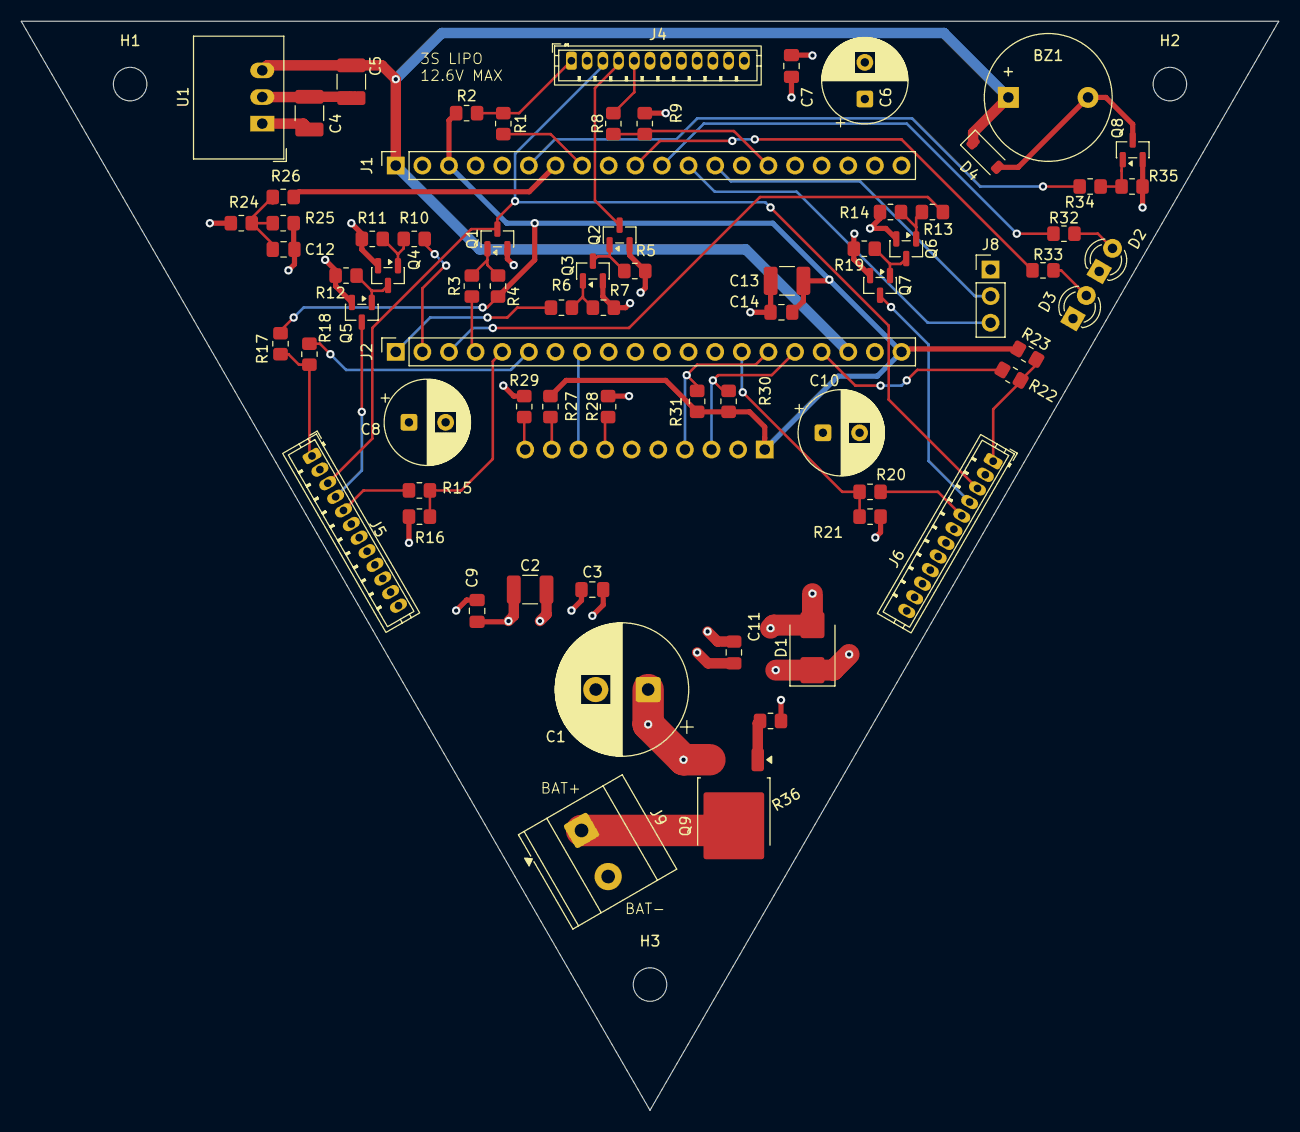
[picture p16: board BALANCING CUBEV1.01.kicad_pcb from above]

Board: 4 copper layers, 120.0 x 103.9 mm, 76 parts (1 on the bottom side), 50 nets.

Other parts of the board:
H1, H2, H3: MountingHole_3.2mm_M3

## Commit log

2026-07-17 Add STM32F411 and BNO080 project plan
    Document project plan for STM32F411/BNO080 self-balancing cube, including goals, scope, architecture, hardware plans, safety requirements, and testing strategies.
2026-07-17 Add comprehensive project README
    Add detailed project overview and bring-up guide for STM32F411/BNO080 self-balancing cube.
2026-09-13 Revise project status in README
    Update project status to reflect current progress on software integration.
2026-09-13 Revise README.md for project status and milestones
    Updated project status, milestones, and documentation details in README.md to reflect current progress in firmware development and software integration.
2026-09-13 Update project plan with current progress and next steps
    Added current progress, immediate next actions, and detailed milestone verification steps. Updated architecture and scope sections to reflect ongoing developments and planned repairs.
2026-09-13 V1 of pcb
    [BALANCING CUBEV1.01.kicad_pcb, BALANCING CUBEV1.01.kicad_sch]
2026-09-13 CAD Main Frame V1
    [Assem1.SLDASM, Assem2.SLDASM, cornerconnectorv0.1.SLDPRT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]
